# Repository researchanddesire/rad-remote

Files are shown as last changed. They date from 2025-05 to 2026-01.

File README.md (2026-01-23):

# RADR - OSSM Wireless Remote
**RADR** (pronounced like "radar") is a user friendly every day sex machine controller for the people. It's designed to simply and easily allow you to control many bluetooth sex toys, without reaching for your cellphone.

It was originally designed to control the [Open Source Sex Machine](https://docs.researchanddesire.com/ossm/guides/getting-started/introduction), but it can control much more!&#x20;

Check out the [user documentation](https://docs.researchanddesire.com/radr/guides/getting-started/introduction)

You can purchase complete remotes and OSSM kits on our shop - [RADR Product Page](https://www.researchanddesire.com/products/radr-ossm-wireless-remote)
<p align="center">
  
</p>

## **Community**
#### [**KinkyMakers Discord Community**](https://discord.gg/VtZcudpxT6)


Most OSSM development takes place through ideas and CAD contributions made by enthusiastic discord members, join the discussion or show off your build!

## Features:
* 4hr battery life
* Auto-pairing with your ossm via bluetooth
* 2" color screen for showing all your settings
* Supports Lovense bluetooth toys (roadmap to support every toy on [buttplug.io](https://buttplug.io/): complete list [here](https://iostindex.com/))
* QWIIC connector for modding and expansion
* Quick start-stop button
* 6-DoF gryo for activity detection (and fun future features)
* Battery fuel gauge
* Haptic feedback
* Audio tone generator

## Why we made it

We wanted an open source wireless remote that could control not just the ossm, but all our fun BLE devices!

## Future Roadmap
* Full [IOST device list](https://iostindex.com) support
* DG labs Coyote e-stim support
* Ability to synchronize or orchestrate multiple devices
* Dynamic pattern alteration on-remote

CERN Open Hardware Licence Version 2 - Strongly Reciprocal
Contributions to this GitHub repository will assume release under the same license.

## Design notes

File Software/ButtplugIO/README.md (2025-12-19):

Device Configurations Attribution

These device configurations were copied from the Buttplug IO project on Tuesday, October 14, 2025.

- Source repository: https://github.com/buttplugio/buttplug
- Project homepage: https://buttplug.io

We love the Buttplug project and are grateful for their work!

Notes

- The schema referenced here is aligned with Buttplug's v4 device configuration schema (`buttplug-device-config-schema-v4.json`).
- Please refer to the Buttplug repository for the latest updates and documentation, as well as licensing information (BSD 3-Clause): https://github.com/buttplugio/buttplug/blob/master/LICENSE

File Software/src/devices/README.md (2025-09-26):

### Devices Module

Technical documentation for developers adding new BLE devices to the remote.

## Supported Devices

- **Research And Desire**
  - **OSSM**: Supported
  - **LKBX**: Pending
  - **DTT**: Pending
- **Lovense**
  - **Domi 2**: Pending

## Registry Overview

Devices are discovered by their primary service UUID and instantiated via a factory registry.

- Registry map: `src/devices/registry.hpp`
- Known service UUIDs: `src/devices/serviceUUIDs.h`
- Device base class: `src/devices/device.h`

## How to Add a Device to the Registry

1. **Obtain the service UUID**

- Use a Bluetooth sniffing/inspection tool (e.g., Bluetility on macOS) to find the device's primary service UUID.

2. **Add the service UUID to `serviceUUIDs.h`**

- Store the UUID as a PROGMEM string constant.

```cpp
// src/devices/serviceUUIDs.h
static const char NEW_DEVICE_SERVICE_ID[] PROGMEM = "xxxxxxxx-xxxx-xxxx-xxxx-xxxxxxxxxxxx";
```

3. **Register a factory in `registry.hpp`**

- Include your device header and add an entry mapping the service UUID to a factory that returns a `Device*` of your concrete class.

```cpp
// src/devices/registry.hpp
#include "your_vendor/your_device/your_device.h"

static const std::unordered_map<String, DeviceFactory> registry = {
    {OSSM_SERVICE_ID, []() -> Device* { return new OSSM(); }},
    {DOMI_SERVICE_ID, []() -> Device* { return new Domi2(); }},
    {NEW_DEVICE_SERVICE_ID, []() -> Device* { return new YourDeviceClass(); }}
};
```

4. **Provide a concrete `Device` implementation**

- Create a header/implementation pair for your device that derives from `Device` (see `src/devices/device.h`).
- **Preferred file structure:**  
  Place your files in  
  `/src/devices/<brand_name>/<device_name>/<device>_device.h`  
  `/src/devices/<brand_name>/<device_name>/<device>_device.cpp`  
  For example, for a "FooBar" device from "Acme", use:  
  `/src/devices/acme/foobar/foobar_device.h`  
  `/src/devices/acme/foobar/foobar_device.cpp`

- Implement input handlers, drawing, and value sync methods as needed.

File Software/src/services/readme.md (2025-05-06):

# Services

Services are global singleton instances of classes that provide functionality to peripherals in the system. They are designed to be shared resources that can be accessed by different parts of the application.

## Key Characteristics

- Services are implemented as global singleton instances
- Typically, there is only one instance of each service running at any time
- By default, services are not thread-safe and require proper synchronization
- Services should be accessed using semaphores to ensure thread safety

## Creating a New Service

### Header File (ServiceName.h)

```cpp
#ifndef SERVICE_NAME_H
#define SERVICE_NAME_H

#include <Arduino.h>
#include "XYZ.h"

// Declare the global service instance, but do not initialize it
extern XYZ serviceNameInstance;

// Optional: Add service configuration or constants
#define SERVICE_NAME_MAX_CONNECTIONS 5

#endif // SERVICE_NAME_H
```

### Implementation File (ServiceName.cpp)

```cpp
#include "ServiceName.h"

// Initialize the global service instance
XYZ serviceNameInstance();

// Optional: Add initialization code in setup()
void setup() {
    serviceNameInstance.begin();
}
```

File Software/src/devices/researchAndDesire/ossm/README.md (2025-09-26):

# OSSM BLE Control Library - Basics

## Service & Device Info

- **Service UUID**: `522b443a-4f53-534d-0001-420badbabe69`
- **Device Name**: "OSSM"
- **Manufacturer**: "Research And Desire"

## Active Characteristics

### 1. Command Characteristic (Write)

- **UUID**: `522b443a-4f53-534d-0002-420badbabe69`
- **Purpose**: Send control commands

**Commands**:

```
set:speed:<0-100>        # Stroke speed percentage
set:stroke:<0-100>       # Stroke length percentage
set:depth:<0-100>        # Penetration depth percentage
set:sensation:<0-100>    # Sensation intensity percentage
set:pattern:<0-6>        # Stroke pattern (0-6)
go:simplePenetration     # Switch to simple penetration mode
go:strokeEngine          # Switch to stroke engine mode
go:menu                  # Return to main menu
```

**Responses**:

- Success: `ok:<original_command>`
- Failure: `fail:<original_command>`

### 2. State Characteristic (Read/Notify)

- **UUID**: `522b443a-4f53-534d-1000-420badbabe69`
- **Purpose**: Monitor device state and settings

**State JSON Format**:

```json
{
  "state": "<state_name>",
  "speed": <0-100>,
  "stroke": <0-100>,
  "sensation": <0-100>,
  "depth": <0-100>,
  "pattern": <0-6>
}
```

**Key States**:

- `idle` - Initializing
- `menu` - Main menu
- `simplePenetration` - Simple penetration mode
- `strokeEngine` - Stroke engine mode
- `error` - Error state

### 3. Speed Knob Config Characteristic (Write)

- **UUID**: `522b443a-4f53-534d-0010-420badbabe69`
- **Purpose**: Configure speed knob behavior

**Values**:

- `true` - Speed knob acts as upper limit for BLE commands (default)
- `false` - Speed knob and BLE speed are independent

### 4. Pattern List Characteristic (Read)

- **UUID**: `522b443a-4f53-534d-2000-420badbabe69`
- **Purpose**: Get available stroke patterns

**Pattern JSON Format**:

```json
[
  { "name": "Simple Stroke", "idx": 0 },
  { "name": "Teasing Pounding", "idx": 1 },
  { "name": "Robo Stroke", "idx": 2 },
  { "name": "Half'n'Half", "idx": 3 },
  { "name": "Deeper", "idx": 4 },
  { "name": "Stop'n'Go", "idx": 5 },
  { "name": "Insist", "idx": 6 }
]
```

## Connection Flow

1. Scan for "OSSM" device
2. Connect and discover service
3. Subscribe to state notifications
4. Read initial state and patterns
5. Send commands as needed

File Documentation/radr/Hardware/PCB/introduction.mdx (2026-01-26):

---
title: "PCB Overview"
description: "Technical documentation for the RADR main PCB (OSSM Wireless v0.4)"
sidebarTitle: "Introduction"
---

This section covers the RADR main PCB design, including schematics, component specifications, and manufacturing files.

## Board Overview

| Specification | Value |
|---|---|
| Board Name | OSSM Wireless |
| Version | v0.4 |
| Microcontroller | ESP32-S3 with PSRAM |
| Design Software | Altium Designer |
| Layer Count | 2 (estimated) |

The RADR PCB integrates all electronics required for a standalone wireless remote controller, including the microcontroller, display interface, power management, user inputs, and feedback systems.

<Frame>
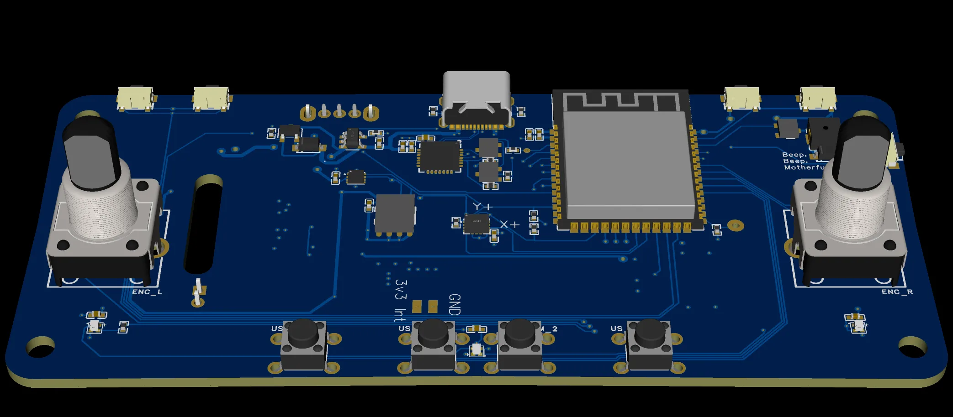
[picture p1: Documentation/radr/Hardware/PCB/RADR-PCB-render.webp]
RADR PCB Render

</Frame>

## Core Components

### Microcontroller

| Parameter | Value |
|---|---|
| MCU | ESP32-S3 |
| Memory | Includes PSRAM |
| Wireless | WiFi + Bluetooth LE |
| Operating Voltage | 3.3V |

The ESP32-S3 provides:
- Dual-core Xtensa LX7 processor
- Integrated Bluetooth Low Energy for device communication
- Sufficient GPIO for all inputs, outputs, and peripherals
- Low-power sleep modes for battery conservation

### Power Management

| Component | Function |
|---|---|
| USB-C Connector | 5V charging input |
| Charging IC | LiPo battery charging |
| MAX17048 | Fuel gauge (battery monitoring) |
| LDO/Regulator | 3.3V system power |

The power system supports:
- USB-C charging (5V input)
- Hardware charging LED indicator
- Precision battery percentage via I²C fuel gauge
- Deep sleep current < 100μA

### Display Interface

| Parameter | Value |
|---|---|
| Display Type | TFT LCD |
| Resolution | 320 x 240 pixels |
| Color Depth | 16-bit (RGB565) |
| Interface | SPI |
| Backlight | PWM-controlled |

### User Inputs

| Input | Type | GPIO |
|---|---|---|
| Left Encoder | Rotary + Push | GPIO 10, 11 |
| Right Encoder | Rotary + Push | GPIO 42, 41 |
| Left Shoulder | Momentary switch | GPIO 48 |
| Right Shoulder | Momentary switch | GPIO 1 |
| Under-Screen Left | Momentary switch | GPIO 38 |
| Under-Screen Center | Momentary switch | GPIO 39 |
| Under-Screen Right | Momentary switch | GPIO 40 |

<Note>
GPIO assignments shown are for v0.4 boards with PSRAM. Earlier v1.x boards use different pins for the left encoder (GPIO 35, 36) and LEDs (GPIO 37).
</Note>

### Feedback Outputs

| Component | Type | GPIO |
|---|---|---|
| Status LEDs | WS2812B RGB (x3) | GPIO 12 |
| Buzzer | Piezoelectric | GPIO 2 |
| Vibration Motor | ERM motor | GPIO 47 |

### Expansion

| Connector | Interface | Purpose |
|---|---|---|
| QWIIC | I²C | External sensors/peripherals |
| USB-C | USB 2.0 | Programming and charging |

## Schematic Sections

The schematic is organized into functional blocks:

| Section | Description |
|---|---|
| Power | USB-C input, charging circuit, voltage regulation |
| MCU | ESP32-S3, crystal, reset, boot selection |
| Display | TFT LCD connector, backlight driver |
| Inputs | Rotary encoders, buttons, pull-up/pull-down resistors |
| Feedback | LED data line, buzzer driver, motor driver |
| Battery | MAX17048 fuel gauge, battery connector |
| Expansion | QWIIC connector, programming header |

## PCB Layout Considerations

### Component Placement

- **MCU** positioned centrally for balanced trace routing
- **USB-C** connector at board edge for accessibility
- **Display connector** oriented for ribbon cable routing to enclosure
- **Battery connector** positioned for internal battery placement
- **QWIIC connector** accessible for expansion modules

### Antenna Considerations

The ESP32-S3 uses an integrated PCB antenna or external antenna (version dependent). The antenna area should be kept clear of:
- Ground planes directly beneath
- Metal enclosure proximity
- High-frequency switching signals

<Warning>
Do not place components or route traces in the antenna keepout zone. This significantly degrades wireless performance.
</Warning>

## Design Files

All design files are available in the GitHub repository:

| File | Format | Description |
|---|---|---|
| PCB - OSSM Wireless v0.4.pcbdoc | Altium Designer | PCB layout with copper, silkscreen, drill files |
| Schematic - OSSM Wireless V0.4.schdoc | Altium Designer | Full schematic capture |
| RADR Schematic - OSSM Wireless V0.4.pdf | PDF | Printable schematic reference |
| RADR BOM - OSSM Wireless - v0.4 - S3.xlsx | Excel | Bill of Materials with part numbers |
| RADR PCB render.png | PNG | 3D render of assembled board |

<Card title="Download Design Files" icon="download" href="https://github.com/researchanddesire/radr-wireless-remote/tree/main/Hardware/Electronics">
Access Altium project files, Gerbers, and BOM on GitHub.
</Card>

## Manufacturing

### PCB Fabrication

Recommended specifications for ordering:

| Parameter | Value |
|---|---|
| Layers | 2 |
| Thickness | 1.6mm |
| Surface Finish | HASL or ENIG |
| Copper Weight | 1oz |
| Solder Mask | Any color |
| Silkscreen | White |

### Assembly Options

| Method | Recommended For |
|---|---|
| Hand Assembly | Prototypes, single units |
| PCBA Service | Production quantities |

<Tip>
Services like JLCPCB and PCBWay offer combined PCB fabrication and assembly. Upload the Gerbers and BOM for a turnkey solution.
</Tip>

### Critical Components

These components require careful attention during assembly:

| Component | Notes |
|---|---|
| ESP32-S3 Module | Check orientation, ensure all pads are soldered |
| USB-C Connector | Requires precise alignment, check for shorts |
| MAX17048 | Small QFN package, needs proper reflow |
| WS2812B LEDs | Heat-sensitive, observe reflow profile |

## Version History

| Version | Changes |
|---|---|
| v0.4 | Current release with ESP32-S3 |

<Note>
Version v0.4 uses the ESP32-S3 variant. The "S3" suffix in the BOM filename indicates this variant.
</Note>

## Troubleshooting

<AccordionGroup>
<Accordion title="Board doesn't power on">
- Check USB-C connection and cable
- Verify 3.3V regulator output
- Check for shorts on power rails
- Ensure battery is connected and charged
</Accordion>

<Accordion title="Display not working">
- Verify ribbon cable connection
- Check SPI signals with oscilloscope
- Confirm backlight PWM signal
- Test display power rails
</Accordion>

<Accordion title="Bluetooth not connecting">
- Check antenna area for shorts or bridges
- Verify ESP32-S3 is programmed correctly
- Ensure no metal near antenna zone
- Test with RF shield removed (if applicable)
</Accordion>

<Accordion title="Battery not charging">
- Verify USB-C CC resistors are present
- Check charging IC connections
- Measure battery voltage at connector
- Confirm charging LED circuit
</Accordion>

<Accordion title="Buttons not responding">
- Check pull-up/pull-down resistors
- Verify GPIO assignments in firmware
- Test continuity from button to MCU
- Check for cold solder joints
</Accordion>
</AccordionGroup>

## Related Documentation

<CardGroup cols={2}>
<Card title="Hardware Overview" icon="microchip" href="/radr/Hardware/getting-started/introduction">
Complete hardware specifications and GPIO mappings.
</Card>

<Card title="Battery & Power" icon="battery-full" href="/radr/Hardware/specifications/battery-and-power">
Detailed power management and charging documentation.
</Card>

<Card title="Printed Parts" icon="cube" href="/radr/Hardware/printed-parts/introduction">
3D printed enclosure that houses the PCB.
</Card>

<Card title="Feedback Systems" icon="lightbulb" href="/radr/Hardware/specifications/feedback-and-indicators">
LED, buzzer, and vibration motor details.
</Card>
</CardGroup>

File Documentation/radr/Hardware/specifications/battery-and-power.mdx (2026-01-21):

---
title: "Battery and Power"
description: "Battery monitoring, charging, and power management for RADR"
sidebarTitle: "Battery & Power"
---

This guide covers RADR's battery system, charging, and power management features.

## Battery System

RADR uses a lithium battery with intelligent monitoring:

| Component | Description |
|---|---|
| Battery Type | Lithium Polymer (LiPo) |
| Fuel Gauge IC | MAX17048 |
| Charging Port | USB-C |
| Charging Indicator | Hardware LED |

### MAX17048 Fuel Gauge

The MAX17048 is a precision fuel gauge that provides:

- **Battery Percentage** — Accurate state-of-charge reading (0–100%)
- **Battery Voltage** — Real-time voltage measurement
- **Low Battery Alerts** — Programmable threshold notifications

<Info>
The fuel gauge uses proprietary algorithms to accurately estimate remaining battery life, compensating for factors like temperature and discharge rate.
</Info>

## Battery Indicator

The battery status is displayed in the status bar at the top of the screen:

| Level | Approximate Range |
|---|---|
| Full | 90–100% |
| High | 60–89% |
| Medium | 30–59% |
| Low | 10–29% |
| Critical | 0–9% |

<Warning>
When battery reaches critical levels, save your session and charge RADR to avoid unexpected shutdown.
</Warning>

## Charging

### USB-C Charging

RADR charges via the USB-C port located at the top of the device, next to the power switch.

- Connect any standard USB-C cable
- Compatible with USB chargers, power banks, and computer USB ports
- Charging works while RADR is powered on or off

### Charging Indicator

A hardware LED indicates charging status:

| LED State | Meaning |
|---|---|
| LED On | Charging in progress |
| LED Off | Fully charged or not connected |

<Note>
The charging LED is separate from RADR's software-controlled RGB LEDs. It's controlled directly by the charging circuit.
</Note>

<Note>
RADR relies on the hardware charging LED rather than software-based charging detection. This provides more accurate and reliable charging status indication.
</Note>

### Charging Tips

<Tip>
For fastest charging, use a USB charger rated for 5V/1A or higher.
</Tip>

<Tip>
You can use RADR while charging, but charging may take longer during active use.
</Tip>

## Power States

RADR has several power states:

### Active (Connected)

- Display on, backlight active
- Bluetooth connected to a device
- LEDs active
- Highest power consumption

### Active (Idle)

- Display on, backlight active
- Bluetooth scanning or in menu
- LEDs in idle pattern
- Medium power consumption

### Sleep Mode

- Display off, backlight off
- Bluetooth disabled
- LEDs off
- Very low power consumption
- GPIO wake enabled

### Power Off

- All systems off
- No power consumption
- Requires power switch to wake

## Deep Sleep Mode

Deep sleep provides significant power savings when you're not using RADR but want quick access later.

<Info>
Technically, RADR uses "light sleep" mode internally rather than true deep sleep. This provides more reliable button wake-up while still achieving very low power consumption. The user experience is the same—the device appears off until a button is pressed.
</Info>

### Entering Sleep Mode

1. From the main menu, select **Sleep**
2. RADR performs the shutdown sequence:
   - Disconnects any connected devices
   - Plays the shutdown buzzer sound
   - Turns off the display backlight
   - Clears all LEDs
   - Enters deep sleep

### Wake Sources

The following buttons can wake RADR from deep sleep:

| Button | GPIO |
|---|---|
| Under-Screen Center | GPIO 39 |
| Under-Screen Left | GPIO 38 |
| Under-Screen Right | GPIO 40 |

Press any of these buttons to wake RADR. The device performs a full restart.

### Sleep vs Power Off

| Feature | Sleep Mode | Power Off |
|---|---|---|
| Power consumption | Very low | None |
| Wake time | ~2 seconds | ~5 seconds |
| Wake method | Button press | Power switch |
| State preserved | No | No |
| Use case | Between sessions | Storage |

<Tip>
Use sleep mode during sessions with breaks. Use the power switch for extended storage.
</Tip>

## Power Management Tips

### Maximizing Battery Life

1. **Use sleep mode** — When taking breaks, put RADR to sleep instead of leaving it idle
2. **Lower brightness** — The display backlight is a significant power consumer
3. **Disconnect when done** — Active Bluetooth connections use more power
4. **Power off for storage** — Use the physical switch for extended storage

### Monitoring Battery Health

- Check battery percentage periodically in the status bar
- Charge before sessions to avoid mid-session interruptions
- Don't let the battery fully deplete frequently

### Charging Best Practices

- Use quality USB-C cables
- Charge in moderate temperatures (avoid extreme heat/cold)
- Any standard USB charger works (5V)
- Fully charge before first use

## Specifications

| Parameter | Value |
|---|---|
| Operating Voltage | 3.3V (regulated) |
| Charging Voltage | 5V USB |
| Deep Sleep Current | < 100μA |
| Active Current | Varies by activity |

## Troubleshooting

<AccordionGroup>
<Accordion title="Battery percentage seems inaccurate">
- The fuel gauge may need calibration after extended storage
- Fully charge, then fully discharge once to recalibrate
- Battery readings stabilize after a few charge cycles
</Accordion>

<Accordion title="RADR won't charge">
- Try a different USB-C cable
- Try a different USB power source
- Ensure the USB-C port is clean and undamaged
- Check that the charging LED illuminates when connected
</Accordion>

<Accordion title="Battery drains quickly">
- Check if you're leaving RADR in active/idle state
- Use sleep mode when not actively controlling a device
- Active Bluetooth connections consume more power
- Older batteries may have reduced capacity
</Accordion>

<Accordion title="Won't wake from sleep">
- Press and hold an under-screen button for 2-3 seconds
- Try the power switch if buttons don't respond
- Ensure the battery isn't completely depleted
</Accordion>
</AccordionGroup>

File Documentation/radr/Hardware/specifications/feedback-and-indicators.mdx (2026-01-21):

---
title: "Feedback and Indicators"
description: "LED colors, buzzer sounds, and vibration patterns for RADR"
sidebarTitle: "Feedback & Indicators"
---

RADR provides visual, audio, and haptic feedback to communicate device state without requiring you to look at the screen.

## LED System

RADR has three RGB LEDs (WS2812B) positioned around the device:

| Position | Location | Primary Purpose |
|---|---|---|
| LED 0 | Left encoder | Speed mode indicator |
| LED 1 | Middle | Connection/play state |
| LED 2 | Right encoder | Active mode indicator |

### LED Colors and Meanings

#### System States

| State | LED | Color | HSV Value | Brightness |
|---|-----|---|---|---|
| Searching/Scanning | All | Blue | 150 | 255 (pulsing) |
| Idle (Main Menu) | All | Soft White | 180 | 50 |
| Device Connected | Middle | White | — | 50 |
| Paused/Stopped | Middle | Red | — | 255 |

#### OSSM Control Modes

When controlling an OSSM, the encoder LEDs indicate the active mode:

| Mode | LED | Color | Description |
|---|-----|---|---|
| Speed | Left | Purple | Always active (speed is always controlled by left encoder) |
| Depth | Right | Coral/Red | Right encoder is adjusting depth |
| Sensation | Right | Blue | Right encoder is adjusting sensation |
| Stroke | Right | Green | Right encoder is adjusting stroke |

### LED Behavior Patterns

| Pattern | Meaning |
|---|---|
| Solid | Static state (connected, paused, etc.) |
| Pulsing | Active scan or searching |
| Quick flash | Feedback for button press or mode change |

## Buzzer Patterns

RADR uses a piezoelectric buzzer (GPIO 2) to provide audio feedback for key events.

### Boot Sound

**Pattern:** 4-note ascending sequence

| Note | Frequency | Duration |
|---|---|---|
| 1 | 523 Hz (C5) | 100ms |
| 2 | 659 Hz (E5) | 100ms |
| 3 | 784 Hz (G5) | 100ms |
| 4 | 1047 Hz (C6) | 150ms |

Played when RADR powers on.

### Shutdown Sound

**Pattern:** 4-note descending sequence

| Note | Frequency | Duration |
|---|---|---|
| 1 | 1047 Hz (C6) | 100ms |
| 2 | 784 Hz (G5) | 100ms |
| 3 | 659 Hz (E5) | 100ms |
| 4 | 523 Hz (C5) | 150ms |

Played when entering sleep mode.

### Device Connected

**Pattern:** 3-note ascending sequence

| Note | Frequency | Duration |
|---|---|---|
| 1 | 1047 Hz (C6) | 80ms |
| 2 | 1319 Hz (E6) | 80ms |
| 3 | 1568 Hz (G6) | 120ms |

Played when successfully connecting to a device.

### Device Disconnected

**Pattern:** 3-note descending sequence

| Note | Frequency | Duration |
|---|---|---|
| 1 | 1568 Hz (G6) | 80ms |
| 2 | 1319 Hz (E6) | 80ms |
| 3 | 1047 Hz (C6) | 120ms |

Played when a device disconnects.

### Paused

**Pattern:** Double beep

| Note | Frequency | Duration |
|---|---|---|
| 1 | 800 Hz | 150ms |
| Gap | — | 100ms |
| 2 | 800 Hz | 150ms |

Played when pausing playback.

### Play/Resume

**Pattern:** Two-tone ascending

| Note | Frequency | Duration |
|---|---|---|
| 1 | 1200 Hz | 100ms |
| 2 | 1400 Hz | 100ms |

Played when resuming playback.

### Mario Coin (Easter Egg)

**Pattern:** Classic coin sound

| Note | Frequency | Duration |
|---|---|---|
| 1 | 2637 Hz (E7) | 80ms |
| 2 | 3136 Hz (G7) | 300ms |

Special feedback for certain interactions.

## Vibration Feedback

RADR includes a vibration motor (GPIO 47) for haptic feedback. Vibration patterns generally mirror buzzer patterns, providing tactile feedback that works without sound.

### Vibration Use Cases

| Event | Vibration |
|---|---|
| Button press | Short pulse |
| Mode change | Quick vibration |
| Connection | Double vibration |
| Pause/Stop | Strong vibration |

### Vibration Pattern Timings

| Pattern | Description | Pulse Durations (ms) |
|---|---|---|
| Single Pulse | Quick tap feedback | 50 |
| Double Pulse | Confirmation feedback | 50, pause 200, 50 |
| Triple Pulse | Strong confirmation | 10, pause 50, 20, pause 50, 30 |
| Error Pulse | Long error indication | 500 |
| Shutdown | Descending pulses | 150, 100, 100, 100 |
| Device Connected | Ascending pulses | 100, 100, 150 |
| Device Disconnected | Descending pulses | 150, 100, 100 |
| Paused | Double pulse | 150, 150 |
| Play/Resume | Quick double pulse | 100, 100 |

<Info>
Vibration feedback helps you operate RADR by feel, especially useful in low-light or when the device is out of direct view.
</Info>

## UI Color Scheme

RADR's display uses a consistent color scheme:

### Background Colors

| Element | Color Code | Description |
|---|---|---|
| Background | 0x10c5 | Dark gray (Gray 900) |
| Text Background | White | Primary text color |
| Secondary Text | 0xDEFB | Light gray |
| Disabled | 0x1082 | Very dark gray |

### OSSM Mode Colors

| Mode | Color Code | Color Name |
|---|---|---|
| Speed | 0x5013 | Royal Purple |
| Depth | 0xE186 | Warm Coral |
| Sensation | 0x3C9F | Ocean Blue |
| Stroke | 0x4E8A | Forest Green |

### State Colors

| State | Color |
|---|---|
| Active/Normal | White |
| Paused/Stopped | Red |
| Disabled | Dark Gray |
| Selected/Highlighted | Accent colors |

## Feedback Timing

| Event | Response Time |
|---|---|
| Button press | < 10ms |
| Encoder change | < 10ms |
| Mode switch | < 50ms |
| LED color change | < 20ms |

## Tips for Using Feedback

<Tip>
Learn the buzzer sounds to operate RADR without looking. The connected sound (ascending) vs disconnected sound (descending) clearly indicates state.
</Tip>

<Tip>
The left LED (purple for speed) and right LED (mode color) tell you which parameter each encoder controls at a glance.
</Tip>

<Tip>
Red middle LED always means paused or stopped. White means active and ready.
</Tip>

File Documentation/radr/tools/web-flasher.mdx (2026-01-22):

---
title: "Web Flasher"
description: "Flash firmware to your RADR wireless remote using the browser-based web flasher utility"
---

import { DeviceFlasher } from '/snippets/shared/device-flasher.jsx';

<DeviceFlasher device="radr" />

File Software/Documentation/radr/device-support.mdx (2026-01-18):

---
title: "Device Support"
description: "Complete list of devices officially supported by the Research And Desire Wireless Remote (RADR)"
---

# Device Support

Every device on this list will be evaluated for RADR compatibility throughout 2025 and 2026.

<Info>
Want us to prioritize a specific device or add one to this list? Contact our support team at [support@researchanddesire.com](mailto:support@researchanddesire.com) or through our [contact form](https://www.researchanddesire.com/contact).
</Info>

## Research And Desire Devices

| Device | Supported | Tested |
| --- | --- | --- |
| [Open Source Sex Machine](https://www.researchanddesire.com/open-source-sex-machine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) | Yes | Yes |
| [Chastity Lockbox](https://www.researchanddesire.com/lockbox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) | Pending | - |
| [Deepthroat Trainer](https://www.researchanddesire.com/deepthroat-trainer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) | Pending | - |

## Third Party Devices

| Device | Supported | Tested |
| --- | --- | --- |
| [DG Labs Coyote E-Stim Powerbox 3.0](https://dungeon-lab.com/e-stim-unit3.0.php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) | Pending | - |

## Buttplug.io Devices

Through our partnership with [Buttplug.io](https://buttplug.io/), we support every device compatible with their Bluetooth protocol. Check their website for the most current compatibility list.

<Warning>
Untested devices display a warning message before use. Only use untested devices during sessions if you understand and accept the associated risks.
</Warning>

### Lovense (Tested)

| Device | Supported | Tested |
| --- | --- | --- |
| [Lovense Domi](https://www.lovense.com/super-powerful-wand-massager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) | Vibration Only | Yes |
| [Lovense Hyphy](https://www.lovense.com/high-frequency-dual-end-vibrator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) | Vibration Only | Yes |
| [Lovense Ferri](https://www.lovense.com/magnetic-panty-vibrator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) | Vibration Only | Yes |

### Lovense (Untested)

| Device | Supported | Tested |
| --- | --- | --- |
| [Lovense Max](https://www.lovense.com/male-masturbators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) | Vibration Only | - |
| [Lovense Edge](https://www.lovense.com/adjustable-prostate-massager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) | Vibration Only | - |
| [Lovense Nora](https://www.lovense.com/rabbit-vibrator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) | Vibration Only | - |
| [Lovense Ambi](https://www.lovense.com/mini-bullet-vibrator-for-clitoral-simulation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) | Vibration Only | - |
| [Lovense Lush](https://www.lovense.com/lush-4-best-bluetooth-remote-controlled-g-spot-vibrator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) | Vibration Only | - |
| [Lovense Hush](https://www.lovense.com/vibrating-butt-plug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) | Vibration Only | - |
| [Lovense Osci](https://www.lovense.com/oscillating-gspot-vibrator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) | Vibration Only | - |
| [Lovense Mission](https://www.lovense.com/mission-2-best-touch-sense-vibrating-dildo-with-suction-cup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) | Vibration Only | - |
| [Lovense Mission 2](https://www.lovense.com/mission-2-best-touch-sense-vibrating-dildo-with-suction-cup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) | Vibration Only | - |
| [Lovense Diamo](https://www.lovense.com/bluetooth-vibrating-cock-ring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) | Vibration Only | - |
| Loveai Dolp | Vibration Only | - |
| [Lovense Dolce](https://www.lovense.com/adjustable-dual-clit-gspot-vibrator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) | Vibration Only | - |
| [Lovense Osci 3](https://www.lovense.com/osci-3-gspot-clitoral-dual-stimulation-rabbit-vibrator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) | Vibration Only | - |
| [Lovense Gush](https://www.lovense.com/handsfree-glans-massager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) | Vibration Only | - |
| [Lovense Gush 2](https://www.lovense.com/gush-2-best-remote-controlled-vibrating-male-penis-massager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) | Vibration Only | - |
| [Lovense Calor](https://www.lovense.com/vibrating-pocket-pussy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) | Vibration Only | - |
| [Lovense Flexer](https://www.lovense.com/dual-wearable-panty-vibrator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) | Vibration Only | - |
| [Lovense Gemini](https://www.lovense.com/app-controlled-vibrating-nipple-clamps-clit-clamps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) | Vibration Only | - |
| [Lovense Gravity](https://www.lovense.com/thrusting-vibrating-dildo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) | Vibration Only | - |
| [Lovense Tenera](https://www.lovense.com/tenera-2-best-clit-sucker-vibrator-clitoral-stimulator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) | Vibration Only | - |
| [Lovense Ridge](https://www.lovense.com/ridge-vibrating-rotating-anal-beads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) | Vibration Only | - |
| [Lovense Lapis](https://www.lovense.com/lapis-strapless-strap-on-double-sided-dildo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) | Vibration Only | - |
| [Lovense Vulse](https://www.lovense.com/vulse-wireless-g-spot-egg-vibrator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) | Vibration Only | - |
| [Lovense Solace](https://www.lovense.com/solace-automatic-hands-free-male-masturbator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) | Pending | - |
| [Lovense Solace Pro](https://www.lovense.com/solace-pro-ai-automatic-blowjob-machine-men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) | Pending | - |

### Other Brands (Pending Support)

<AccordionGroup>
<Accordion title="Adrien Lastic">
- Adrien Lastic Palpitation
- Adrien Lastic Revelation
</Accordion>

<Accordion title="Amorelie Joy">
- Amorelie Joy Move
- Amorelie Joy Cha-Cha
- Amorelie Joy Boogie
- Amorelie Joy Shimmer
- Amorelie Joy Grow
- Amorelie Joy Shuffle
- Amorelie Joy Salsa
</Accordion>

<Accordion title="Adorime">
- Adorime Wearable Egg Vibrator
- Adorime Male Masturbator
- Adorime Penis Vibrator
- Adorime Anal Vibrator
- Adorime Chastity Cage
- Adorime Penis Helmet Vibrator
- Adorime G-spot Rabbit Dildo Vibrator
- Adorime Backy
</Accordion>

<Accordion title="Auxfun / Hismith / Defyeah / Wildolo">
- Auxfun Sex Machine
- Hismith Sex Machine
- Hismith Mini Sex Machine
- Hismith Servo Sex Machine
- Hismith Ukulele
- Hismith Pro Traveler
- Hismith Capsule
- Hismith Thrusting Cup
- Hismith G011
- Wildolo Device
- Defyeah Horizontal Sex Machine ASFO16
</Accordion>

<Accordion title="Cachito">
- Cachito Lure Tao
- Cachito Ice Cream
</Accordion>

<Accordion title="The Cowgirl / Unicorn">
- The Cowgirl Cone
- The Cowgirl
- The Unicorn
</Accordion>

<Accordion title="Cueme">
- Cueme Mens
- Cueme Bra
- Cueme Womans
</Accordion>

<Accordion title="Eropair / Sinloli">
- Eropair Rabbit Vibrator
- Eropair Thrusting Vibrating Dildo
- Eropair Cup
- Sinloli Automatic Sex Doll
- Sinloli Cosima
- Sinloli Ethel
- Sinloli Aston
- Sinloli Piupiu
</Accordion>

<Accordion title="Foreo">
- Foreo LUNA fofo
- Foreo LUNA play smart 2
- Foreo LUNA 3 / 3 plus / 3 men / 3 mini
- Foreo LUNA 4 / 4 plus / 4 men / 4 mini
- Foreo UFO / UFO mini / UFO 2
- Foreo UFO 3 / 3 go / 3 led / 3 mini
- Foreo BEAR / BEAR mini
- Foreo BEAR 2 / 2 go / 2 eyes / 2 body
- Foreo KIWI / KIWI derma
</Accordion>

<Accordion title="Galaku">
- Galaku Nebula
- Galaku Shana
- Galaku Miya
- Galaku Capsule lipstick
- Galaku Vitality Cat
- Galaku Phantom X
- Galaku Vitality Strawberry
- Galaku Little Magic Box
- Galaku Little Whale
- Galaku Happy Vibrator
- Galaku Xiaobao Beans
- Galaku Capsule Vibrator
- Galaku Ice cone miniAV stick
- Galaku mini ice cream cone
- Galaku Shia's Collar
- Galaku Vitality Bird (Second Generation)
- Galaku Octopus glans massager
- Galaku Alice
- Galaku Unicorn Butt Plug
- Galaku Ace
- Galaku Little cute turtle
- Galaku Little Bullet
- Galaku Joy Vibrator
- Galaku Bowling
- Galaku Mixin Controller
- Galaku Hua Chao Brush
- Galaku Dream Vibration
- Galaku Rogue Rabbit
- Galaku Ballet Vibrator
- Galaku Donut
- Galaku Flirting Pen
- Galaku Ball vibrator
- Galaku Cyberpunk Airplane Cup
- Galaku Vitality Cute Pet
- Galaku Little gourd vibrating egg
- Galaku little kitten
- Galaku Little Dinosaur
- Galaku Bell sucking
- Galaku Ring vibration
- Galaku Erection Booster
- Galaku Gyoyo-G
- Galaku Gyoyo
- Galaku Pinky stick
- Galaku Little Turtle Stick
- Galaku Xiao Xian Wan
- Galaku Mitang
- Galaku Zaku Aircraft Cup
- Galaku Mecha
- Galaku Little Devil
- Galaku Athena
- Galaku Vitality Octopus II
- Galaku Little Dolphin
- Galaku Unicorn / Unicorn II
- Galaku Queen Bee Gun
- Galaku Freya
- Galaku Rhino Prostate Massager
- Galaku Armoured-ONE
- Galaku Flower Season
- Galaku Little Rubik's Cube
- Galaku Small powder cake
- Galaku Milly
- Galaku Rhinoceros Back Court
- Galaku Phantom / Phantom PLUS
- Galaku F1 Aircraft Cup
- Galaku Scepter AV Stick
- Galaku Classic vibration-absorbing AV state
- Galaku New series of vibrators
- Galaku Aurora Aircraft Cup
- Galaku Cannon-GT
- Galaku Vision
- Galaku Dimension No. 1
- Galaku Starry Sky CUP
- Galaku Panty Vib
</Accordion>

<Accordion title="iToys">
- iToys Seagull
- iToys Twinkling Stars
</Accordion>

<Accordion title="JoyHub">
- JoyHub Pearlconch / Pearlconch L
- JoyHub Piet 2
- JoyHub Panther
- JoyHub Petite Rose
- JoyHub Moon Horn
- JoyHub Mecha
- JoyHub Lagoon
- JoyHub VibTrefoil
- JoyHub Firedragon
- JoyHub Deena
- JoyHub Cherly / Cherly 2c
- JoyHub Pathfinder / Pathfinder 2 / Pathfinder 3
- JoyHub Angela
- JoyHub Verax / Verax 2 / Verax 4
- JoyHub Euphoric / Euphoric 2 / Euphoric 3
- JoyHub RoseBUD
- JoyHub Morningbuds
- JoyHub Rhythmic 2 / Rhythmic 3 / Rhythmic 4
- JoyHub Virtuoso / Virtuoso 2
- JoyHub Dyllis
- JoyHub PhoenixGP
- JoyHub Fable Dragon
- JoyHub Faunus
- JoyHub Velvet Rabbit
- JoyHub Vivid Pulse
- JoyHub Violet Vine
- JoyHub VibSiren / VibSiren 2
- JoyHub Veemy
- JoyHub Viball
- JoyHub Vase / Vase 2
- JoyHub Vortex 2s
- JoyHub Lips
- JoyHub Torin
- JoyHub VBarbie / VBarbie p
- JoyHub Royaleye
- JoyHub Norma
- JoyHub Pau
- JoyHub Petalwish 2 / Petalwish 3
- JoyHub Marshal
- JoyHub Vince
- JoyHub Dallin
- JoyHub Maynor
- JoyHub Palmyra
- JoyHub Xylia
- JoyHub Maiden
- JoyHub Viele / Viele 3
- JoyHub Troi
- JoyHub Tanmouth
- JoyHub Marcela
- JoyHub Vita
- JoyHub Lach
- JoyHub Markel
- JoyHub Pipes
- JoyHub Vigo
- JoyHub Starfish
- JoyHub Resi Ring 2
- JoyHub RoseLin
- JoyHub Perseus
- JoyHub Melody
- JoyHub Rosella 2
- JoyHub Velocity
- JoyHub ElixirEgg
- JoyHub Retro Guard
- JoyHub TrueForm / TrueForm 3
- JoyHub Rainbow
- JoyHub Black Bull
- JoyHub Peacock
- JoyHub Mace
- JoyHub Tarian
- JoyHub Torrian
- JoyHub Rayen
- JoyHub Mackay
- JoyHub Rowdy 3
- JoyHub Eclipse
- JoyHub Scarlett
- JoyHub Tarik
- JoyHub Urica Guard / Urica Guard 2
- JoyHub Viva
- JoyHub Ryden
- JoyHub Peachy
- JoyHub Enam
- JoyHub Viv
- JoyHub Vivara
- JoyHub Explorer 2
- JoyHub Divers
- JoyHub Vortex Tongue
- JoyHub Mysticolor
- JoyHub Vivid Wings
- JoyHub Mariner
- JoyHub MarsLion / Mars Lion 2
- JoyHub Pul
- JoyHub Rose Love
- JoyHub Edasich
- JoyHub Mars
- JoyHub Martino
- JoyHub Myrna
</Accordion>

<Accordion title="Kiiroo / OhMiBod / Hot Octopuss">
- Luxus
- Kiiroo Pearl / Pearl 2 / Pearl 2.1 / Pearl 2+ / Pearl 3
- Kiiroo Onyx / Onyx 2 / Onyx 2.1 / Onyx+ / Onyx+ Realm Edition
- Kiiroo Titan / Titan 1.1
- Kiiroo Cliona
- Kiiroo Keon
- Kiiroo PleasureDrive
- Fleshlight Launch
- OhMiBod Fuse / Fuse 1.1
- OhMiBod Esca 2
- OhMiBod Lumen
- OhMiBod NEX|2 / NEX|3
- OhMiBod Foxy
- OhMiBod Chill
- OhMiBod Sphinx
- PornHub Virtual Rabbit
- PornHub Virtual Blowbot
- Hot Octopuss Pulse Solo Interactive
</Accordion>

<Accordion title="Kisstoy">
- Kisstoy Lost (Vibrating)
- Kisstoy Lost (Sucking)
- Kisstoy Lost (Insertable)
</Accordion>

<Accordion title="Kuirkish">
- Kuirkish Imp 3
</Accordion>

<Accordion title="LELO">
- Lelo F1s V2 / V3
- Lelo F2S
- Lelo Ida Wave
- Lelo Tor 3
- Lelo Hugo 2
- Lelo Enigma Double Sonic
- Lelo Gigi 3
- Lelo Liv 3
</Accordion>

<Accordion title="Libo">
- Libo Elle / Elle 2
- Libo Lottie
- Libo LuLu
- Libo Lina
- Libo Adel
- Libo Lily
- Libo Lucy
- Libo Lara
- Libo Feather
- Libo LaLa
- Libo Carlos
- Libo Selina
- Libo Miao
</Accordion>

<Accordion title="Love Distance">
- Love Distance Reach G
- Love Distance Reach
- Love Distance Mag
- Love Distance Span
- Love Distance Range
- Love Distance Join G
- Love Distance Link
- Love Distance Grasp
- Love Distance Receive
</Accordion>

<Accordion title="Lovehoney">
- Lovehoney Desire Prostate Vibrator
- Lovehoney Desire Knicker Vibrator
- Lovehoney Desire Love Egg
</Accordion>

<Accordion title="Lovense Connect">
- Lovense Connect Max
- Lovense Connect Edge
- Lovense Connect Nora
- Lovense Connect Ambi
- Lovense Connect Lush
- Lovense Connect Hush
- Lovense Connect Domi
- Lovense Connect Osci
- Lovense Connect Mission
- Lovense Connect Ferri
- Lovense Connect Diamo
- Lovense Connect Loveai Dolp
- Lovense Connect Sex Machine / Mini Sex Machine
- Lovense Connect Dolce
- Lovense Connect Gush
- Lovense Connect Hyphy
- Lovense Connect Calor
- Lovense Connect Flexer
- Lovense Connect Gemini
- Lovense Connect Gravity
- Lovense Connect Ridge
- Lovense Connect Lapis
- Lovense Connect Vulse
- Lovense Connect Solace
</Accordion>

<Accordion title="Luvmazer">
- Luvmazer Finger Magic
- Luvmazer Cat Paw
- Luvmazer Cock Ring
- Luvmazer Interstellar
</Accordion>

<Accordion title="MagicMotion / FitCute / G Vibe / FunTown / Femometer">
- MagicMotion Smart Bean
- MagicMotion Smart Mini Vibe
- MagicMotion Vini
- MagicMotion Flamingo
- MagicMotion Kegel
- MagicMotion Dante/Candy/Rise
- MagicMotion Wand
- MagicMotion Fugu
- MagicMotion Xone
- MagicMotion Awaken
- MagicMotion Equinox
- MagicMotion Solstice / Solstice X
- MagicMotion Eidolon
- MagicMotion Zenith
- MagicMotion Bunny
- MagicMotion Sundae
- MagicMotion Kegel Coach
- MagicMotion Lotos
- MagicMotion Nyx
- MagicMotion Umi
- MagicMotion Crystal
- MagicMotion Bobi
- FitCute Kegel Rejuve
- G Vibe Gballs 2 / Gballs 3
- FunTown Caleo
- FunTown Jive
- Femometer Lilac
</Accordion>

<Accordion title="Meese / Sistalk / Tracy's Dog">
- Meese Tera
- Meese Modo
- Sistalk MonsterPub 2 Doctor Whale
- Sistalk MonsterPub Magic Kiss
- Sistalk MonsterPub 2 Mister Devil
- Sistalk MonsterPub Baby Youth Health
- Sistalk MonsterPub KiniCat
- Sistalk MonsterPub BeatHeart
- Sistalk MonsterPub 1P Mister Devil
- Sistalk MonsterPub Sweet
- Sistalk MonsterPub Amazing
- Sistalk MonsterHub Tornado
- Sistalk MonsterPub Pop
- Tracy's Dog Surreal
- Tracy's Dog Craybit Pro
</Accordion>

<Accordion title="Motorbunny / Dream Lover">
- Motorbunny Classic
- Motorbunny Buck
- Dream Lover Archer 2
</Accordion>

<Accordion title="MysteryVibe">
- MysteryVibe Tenuto Mini
- MysteryVibe Crescendo / Crescendo 2
- MysteryVibe Tenuto / Tenuto 2
- MysteryVibe Legato
- MysteryVibe Molto
- MysteryVibe Poco
</Accordion>

<Accordion title="Patoo / Picobong">
- Patoo Carrot
- Patoo Vibrator
- Patoo Bean Sprout
- Patoo Devil
- Picobong Blow hole
- Picobong Diver
- Picobong Life guard
- Picobong Surfer
</Accordion>

<Accordion title="Pink Punch / Sakuraneko">
- Pink Punch Sunset Mushroom
- Pink Punch Peachu
- Pink Punch Dream Bunny
- Pink Punch Peacaron
- Sakuraneko Korokoro
- Sakuraneko Nukunuku
- Sakuraneko Dokidoki
- Sakuraneko Koikoi
</Accordion>

<Accordion title="Satisfyer">
- Satisfyer Hot Spot
- Satisfyer Heated Affair
- Satisfyer Big Heat
- Satisfyer Heated Thrill
- Satisfyer Hot Bunny
- Satisfyer Heat Climax / Heat Climax+
- Satisfyer Hot Passion
- Satisfyer Haute Couture+
- Satisfyer High Fashion+
- Satisfyer Prêt-à-porter+
- Satisfyer Love Triangle
- Satisfyer Curvy 1+ / 2+ / 3+
- Satisfyer Double Wand-er
- Satisfyer Double Joy / Double Fun / Double Love
- Satisfyer Hot Lover
- Satisfyer Mono Flex / Double Flex
- Satisfyer Heat Wave
- Satisfyer Little Secret / Sexy Secret / Top Secret / Top Secret+
- Satisfyer Strong One / Mighty One / Powerful One / Royal One
- Satisfyer Signet Ring
- Satisfyer Dual Love / Dual Pleasure
- Satisfyer Hero+ / Knight+ / Newcomer+
- Satisfyer Plug-ilicious 1 / 2
- Satisfyer E-Love Foreplay / G-Hunter / G-Hunter+ / G-Spotter / G-Spotter+ / Story
- Satisfyer Love Birds 1 / 2 / Vary
- Satisfyer Ribbed Petal / Shiny Petal / Smooth Petal
- Satisfyer Men Vibration+
- Satisfyer Power Plug
- Satisfyer Rotator Plug 1+ / 2+
- Satisfyer Deep Diver
- Satisfyer Sweet Seal
- Satisfyer Trendsetter
- Satisfyer Twirling Joy
- Satisfyer Ultra Power Bullet 8
- Satisfyer Double Desire / Double Lust
- Satisfyer Epic Duo
- Satisfyer Pleasure Wand+
- Satisfyer Bullseye
- Satisfyer Sunray
- Satisfyer Curvy Trinity 5+
- Satisfyer Intensity Plug
- Satisfyer Power Masturbator
- Satisfyer Hug me
- Satisfyer Air Pump Bunny 5+ / Air Pump Vibrator 5+ / Air Pump Booty 5+
- Satisfyer Threesome 4
- Satisfyer G-Spot Flex 4+ / 5+
- Satisfyer Pro+ Wave 4
- Satisfyer Mini Wand-er+
- Satisfyer Tropical Tip
- Satisfyer Twirling Pro+
- Satisfyer Perfect Pair 4
- Satisfyer Booty Absolute Beginners 5
- Satisfyer Rrrolling Sensation
- Satisfyer Pro 2 Gen 3
</Accordion>

<Accordion title="SayberX / Sensee / Easylive / Qingnan">
- SayberX
- Sayber X-Ring
- Sensee Capsule
- Sensee Astronaut
- Sensee No8
- Sensee Voice-Interactive Female Vibrator
- Sensee Moonlight
- Sensee Little Seahorse
- Sensee Dream Stick
- Easylive Vader
- Qingnan #16
</Accordion>

<Accordion title="Secret Lover">
- Secret Lover Simon
- Secret Lover Betty
- Secret Lover Kevin
</Accordion>

<Accordion title="Sexverse / VVD / Cooxer / Duopeak">
- Sexverse Rex
- Sexverse Cali
- Sexverse Olis
- Sexverse BuCUE
- Sexverse Tadpole
- Sexverse Upton
- Sexverse Una
- Sexverse HH010
- Sexverse Tay 1 / 6 / 9
- Sexverse Zeus
- Sexverse Black Knight / Dark Knight
- VVD Vkini
- Cooxer Bullet Vibe
- Duopeak Saphette
</Accordion>

<Accordion title="Svakom / ToyCod / BeYourLover / Fantasy Cup / Coleur Dor / Momonii">
- Svakom Pulse Lite Neo
- Svakom Pulse Union
- Svakom Pulse Galaxie
- Svakom Mimiki
- Svakom Sam Neo 2 / Sam Neo 2 Pro
- Svakom Ella / Ella Neo
- Svakom Phoenix Neo / Phoenix Neo 2
- Svakom Emma Neo / Emma Neo 2 / Mini Emma Neo
- Svakom Viviana
- Svakom Edeny
- Svakom Tammy Pro
- Svakom Vick Neo / Vick Neo 2
- Svakom Aravinda
- Svakom Winni 2
- Svakom Cici 2 / Cici+ 2
- Svakom Hannes Neo
- Svakom Alberta
- Svakom Erica
- Svakom Chika
- Svakom Mora Neo
- Svakom Trysta Neo
- Svakom Coco Pro
- Svakom Echo 2
- Svakom Iker Neo
- ToyCod Vanesia
- ToyCod Barzillai
- ToyCod Clara
- BeYourLover Kyukyu
- BeYourLover Naughty Clock Vibrator / Sucker
- Fantasy Cup Theodore
- Coleur Dor VX045A / HX029A / VX236A
- Momonii Agatha
</Accordion>

<Accordion title="Synchro / TryFun / VibCrafter / Vibratissimo">
- Synchro Exchange
- TryFun Surge Pro
- VibCrafter Harlow
- VibCrafter Hayden
- VibCrafter Nidalee
- VibCrafter Janna
- Vibratissimo Licker
- Vibratissimo Rabbit
</Accordion>

<Accordion title="Vorze / Adult Festa">
- Vorze Bach
- Vorze A10 Cyclone SA
- Vorze UFO SA / UFO TW
- Vorze Piston
- Adult Festa Rocket
</Accordion>

<Accordion title="We-Vibe">
- We-Vibe Melt
- We-Vibe Moxie
- We-Vibe Vector
- We-Vibe Wand / Wand 2
- We-Vibe Bond
- We-Vibe Nova / Nova 2
- We-Vibe Jive / Jive 2
- We-Vibe Sync / Sync 2 / Sync Lite
- We-Vibe Bloom
- We-Vibe Ditto
- We-Vibe Pivot
- We-Vibe Rave
- We-Vibe Verge
- We-Vibe Wish
- We-Vibe 4 Plus
- We-Vibe Gala
</Accordion>

<Accordion title="Zalo">
- Zalo Queen
- Zalo King
- Zalo Jeanne
</Accordion>
</AccordionGroup>

<Note>
Affiliate links are marked with a star icon and help fund continued development of this project.
</Note>

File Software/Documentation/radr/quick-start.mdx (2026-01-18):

---
title: "Quick Start"
description: "Get your Research And Desire Wireless Remote (RADR) set up and connected to your OSSM or Bluetooth device in minutes."
---

<iframe
  className="w-full aspect-video rounded-xl"
  src="https://www.youtube.com/embed/SqUHOGLTgAE"
  title="RADR Quick Start Video"
  frameBorder="0"
  allow="accelerometer; autoplay; clipboard-write; encrypted-media; gyroscope; picture-in-picture"
  allowFullScreen
></iframe>

<Accordion title="Video transcript">
Today I have the new Research and Desire wireless remote, also called the RADR. And I'm super excited to show you how it connects with both OSSM and also a wireless Bluetooth device like the Domi right here. In order to control the OSSM, you have to make sure that you have updated your firmware to the newest version. Once you've done that, just make sure that your machine is plugged in and turned on. And I'll show you how it connects really quickly. I'm turning on the power switch. And as you can see, it is automatically searching for the device and voila, it is connected. You don't have to do anything else. I'll go over some of the specifics of the remote now. So the left hand knob always is controlling the speed and the right hand knob will toggle back and forth depth, sensation, and stroke. So I'm just going to turn up the speed a little bit here so you can see that's going. And right now I'm currently in stroke. As I'm moving the stroke knob, you can see one of the rings is going up and down. So you can always kind of see where you're at in terms of how much stroke you have on. In terms of these buttons here, this button here is pattern. So if you click into it, you'll be able to take a look at all the different patterns. and you can select one using the pattern button again. This button here is stop and go, pause or play. So there we go, it stopped your OSSM immediately and then it says if you click it again, device is stopped. Once it stops you can just like turn up the speed again and it'll start working again. And that's it for controlling the OSSM. So I also wanted to show you how to control the Domi, so I'm just gonna turn this off and I'm gonna unplug my OSSM. Alright, so now I've got my Domi and I'm just gonna turn it on. So it's on now and I'm gonna just do the same thing like I did with the OSSM. I turn it on and it's gonna automatically search for the device. And look at that, it is connected to my Domi now. I can play with the knob. And there's that stop button as well. And there you have it, you have the new wireless remote radar connecting both to the Domi and to the OSSM.
</Accordion>

The RADR was originally designed as a wireless, user-friendly controller for the OSSM (Open-Source Sex Machine), created in partnership with The Kinkymakers. It has since evolved into a versatile wireless controller for a range of Bluetooth-enabled devices using the ButtplugIO protocol.

This guide walks you through pairing your RADR with the OSSM and getting started immediately. The same process applies to other supported devices like the Lovense Domi 2.

<Card title="Device support" icon="bluetooth" href="./device-support">
View the complete list of supported Bluetooth devices.
</Card>

## Getting started

### Remote layout

<Frame>
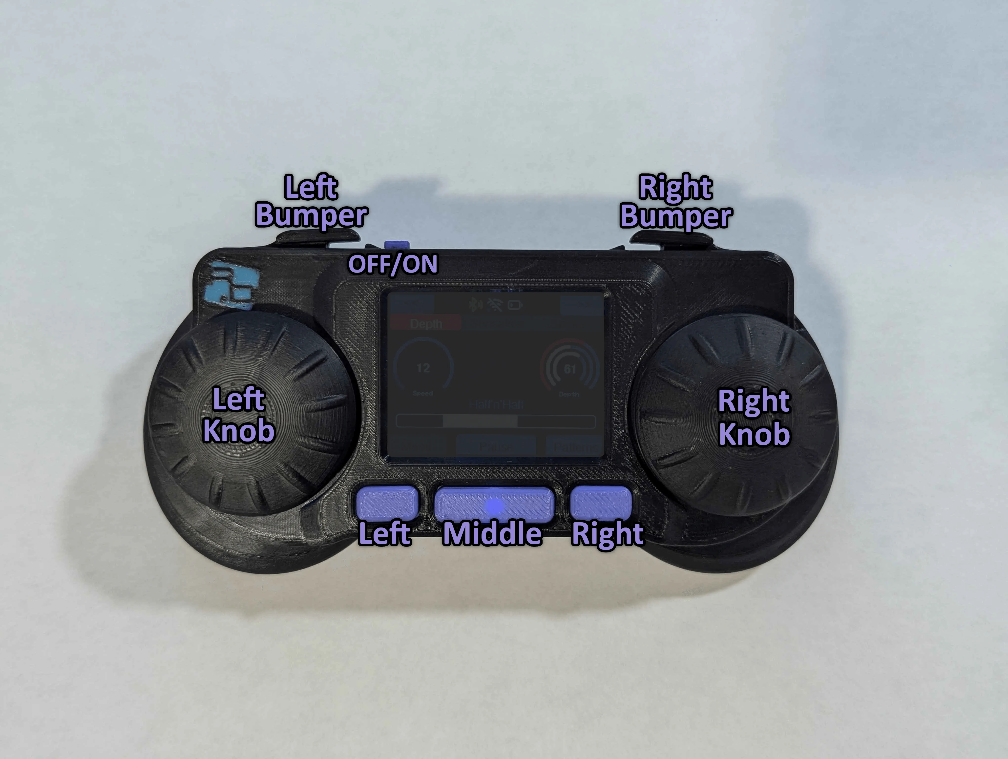
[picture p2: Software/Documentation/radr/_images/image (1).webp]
RADR remote control layout showing buttons, knobs, and screen placement

</Frame>

The RADR features an intuitive, tactile design with the following controls:

**Top edge:**
- **Left Bumper** — Located on the left side
- **Power Switch** — Above the screen, to the left of the USB-C port
- **Right Bumper** — Located on the right side

**Front face:**
- Full-color LCD screen centered on the device
- Three buttons directly below the screen:
  - **Left Button** — Home / Back
  - **Middle Button** — Pause / Stop
  - **Right Button** — Menu / OK

**Sides:**
- **Left Knob** (encoder) — Controls speed
- **Right Knob** (encoder) — Adjusts depth, sensation, or stroke

### Powering on

<Steps>
<Step title="Charge your RADR">
Connect your RADR to a power source using a USB-C cable and allow it to charge.
</Step>

<Step title="Turn on the remote">
Flip the **Power Switch** to the right (toward the USB-C port) to power on the device.
</Step>

<Step title="Wait for device discovery">
Once powered on, your RADR automatically scans for nearby supported Bluetooth devices.

<Info>
RADR only searches for officially supported devices. It won't connect to unsupported Bluetooth hardware.
</Info>
</Step>
</Steps>

<Card title="Device support" icon="list-check" href="./device-support">
Check which devices are compatible with RADR.
</Card>

### Pairing with the OSSM

<Steps>
<Step title="Update your OSSM firmware">
Ensure your OSSM is running firmware version 2.0.0 or higher.

<Card title="Flashing your OSSM" icon="microchip" href="/ossm/Software/getting-started/introduction">
Follow our firmware update guide if you need to update your OSSM.
</Card>
</Step>

<Step title="Power on and home the OSSM">
Turn on your OSSM and allow it to complete its homing procedure. Keep the device powered on.
</Step>

<Step title="Automatic pairing">
With both devices powered on and nearby, they will automatically pair within seconds.

<Check>
When connected, your RADR displays the Play Controls screen.
</Check>
</Step>
</Steps>

## Play controls

When your RADR and OSSM are paired, you'll see the Play Controls screen.

<Frame>
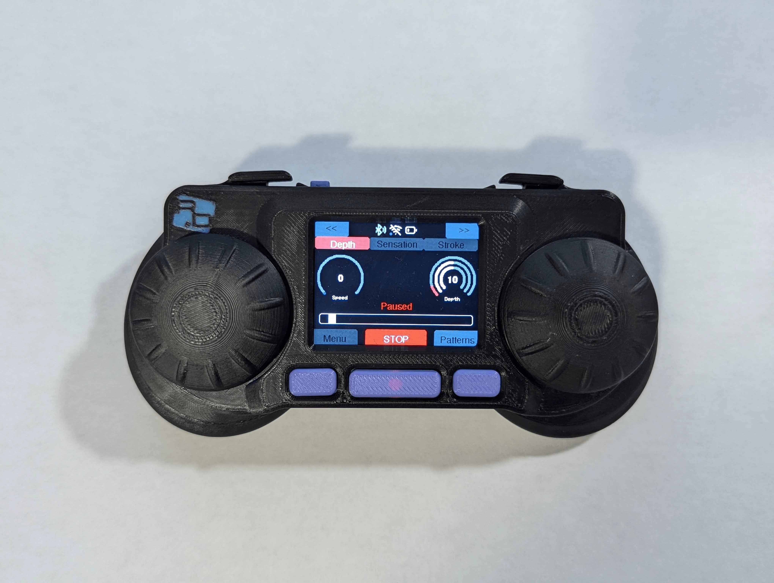
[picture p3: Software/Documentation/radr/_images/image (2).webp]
RADR play controls screen showing speed and adjustment indicators

</Frame>

| Control | Action |
|---|---|
| **Left Knob** | Adjust speed |
| **Right Knob** | Adjust current mode (Depth, Sensation, or Stroke) |
| **Left/Right Bumper** | Cycle through adjustment modes |
| **Left Button** | Open OSSM Device Settings (coming soon) |
| **Middle Button** | Single press: Pause session (increase speed to resume). Double press: Stop session and reset to defaults |
| **Right Button** | Open Pattern Mode |

## Pattern mode

<Frame>
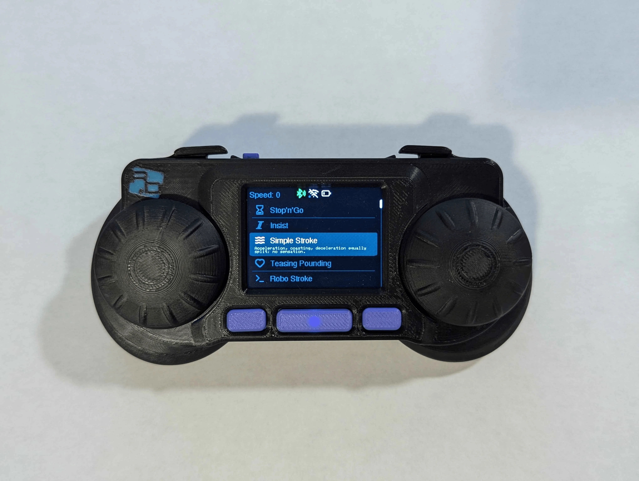
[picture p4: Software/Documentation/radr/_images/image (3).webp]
RADR pattern mode screen showing available motion patterns

</Frame>

Press the **Right Button** to enter Pattern Mode and choose from a library of built-in motion patterns.

| Control | Action |
|---|---|
| **Left Knob** | Adjust speed |
| **Right Knob** | Scroll through patterns |
| **Left/Right Bumper** | No action |
| **Left Button** | Exit to Play Controls without applying |
| **Middle Button** | Pause session and exit to Play Controls |
| **Right Button** | Select highlighted pattern |

<Tip>
More patterns are being added regularly. Check for firmware updates to access new pattern libraries.
</Tip>

## Connection recovery

If your RADR loses connection during use—whether due to distance, power loss, or Bluetooth interference—it will automatically attempt to reconnect within 2–5 seconds.

<Warning>
As a safety precaution, if the connection isn't restored quickly, the OSSM will gradually reduce speed and pause the session.
</Warning>

If reconnection fails, power-cycle both the RADR and your device. They will pair automatically when restarted.

## Next steps

Once you've completed setup:

- Your RADR is charged and paired
- Your OSSM (or other supported device) is running the latest firmware
- You can control your device wirelessly without cables or legacy displays

<CardGroup cols={2}>
<Card title="Device support" icon="bluetooth" href="./device-support">
Explore all compatible devices.
</Card>

<Card title="Firmware updates" icon="download" href="/ossm/Software/getting-started/introduction">
Keep your devices up to date.
</Card>
</CardGroup>

Enjoy your Research And Desire Wireless Remote—designed for seamless, intuitive control across the RAD ecosystem.

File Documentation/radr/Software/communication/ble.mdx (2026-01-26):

---
title: "Bluetooth Communication"
description: "BLE protocol details and device communication for RADR"
sidebarTitle: "BLE Protocol"
---

This document covers the Bluetooth Low Energy (BLE) communication protocols used by RADR to communicate with supported devices.

## BLE Overview

RADR uses Bluetooth Low Energy (BLE) for all device communication. As a BLE central device, RADR scans for and connects to peripheral devices like the OSSM and Lovense toys.

| Parameter | Value |
|---|---|
| BLE Role | Central |
| Device Name | OSSM-REMOTE |
| Transmit Power | 9 dBm |
| Stack | NimBLE |

## Scan Parameters

| Parameter | Value |
|---|---|
| Scan Interval | 100ms |
| Scan Window | 100ms |
| Scan Type | Active |
| Scan Duration | 5000ms (5 seconds) |

During active scanning, RADR sends scan request packets to devices to retrieve their full advertising data, including device names.

## Connection Parameters

RADR uses optimized connection parameters for responsive control:

| Parameter | Value | Description |
|---|---|---|
| Min Interval | 12 | 15ms minimum connection interval |
| Max Interval | 12 | 15ms maximum connection interval |
| Latency | 0 | No slave latency (immediate responses) |
| Supervision Timeout | 150 | 1500ms timeout for lost connections |
| Connect Timeout | 5000ms | Maximum time to establish connection |

The 15ms connection interval provides responsive control with minimal latency between encoder turns and device response.

## Device Discovery

RADR identifies supported devices by their advertised service UUIDs:

### Research And Desire Devices

| Device | Service UUID |
|---|---|
| OSSM | `522B443A-4F53-534D-0001-420BADBABE69` |
| LKBX | Pending implementation |
| DTT | Pending implementation |

### Lovense Devices

| Device | Service UUID |
|---|---|
| Domi 2 | `57300001-0023-4BD4-BBD5-A6920E4C5653` |
| Other | Via Buttplug.io registry |

### Buttplug.io Devices

Devices supported via the Buttplug.io protocol are identified using UUIDs from the dynamic registry (`registry.json`). This registry can be updated via firmware updates without code changes.

## OSSM Protocol

RADR communicates with OSSM using a custom BLE protocol:

### Service Structure

```
Service: 522B443A-4F53-534D-0001-420BADBABE69
├── Position Characteristic
├── Speed Characteristic
├── Depth Characteristic
├── Sensation Characteristic
├── Stroke Characteristic
└── Pattern Characteristic
```

### Command Format

Commands are sent as byte arrays to the appropriate characteristic:

| Parameter | Data Type | Range |
|---|---|---|
| Speed | uint8_t | 0-100 |
| Depth | uint8_t | 0-100 |
| Sensation | uint8_t | 0-100 |
| Stroke | uint8_t | 0-100 |
| Pattern | uint8_t | Pattern index |

### Pattern Selection

Patterns are selected by index:

| Index | Pattern Name |
|---|---|
| 0 | Simple Stroke |
| 1 | Teasing Pounding |
| 2 | Robo Stroke |
| 3 | Half'n'Half |
| 4 | Deeper |
| 5 | Stop'n'Go |
| 6 | Insist |

## Lovense Protocol

For Lovense devices with direct integration (Domi), RADR uses the Lovense BLE protocol:

### Vibration Control

```
Command: Vibrate:{level};
Level: 0-16
```

### Battery Query

```
Command: Battery;
Response: {percentage}
```

### Power Control

```
Command: PowerOff;
```

## Buttplug.io Devices

For devices supported via Buttplug.io, RADR implements a subset of the Buttplug protocol:

- **Vibrate** — Set vibration level (0-1 float, mapped to device range)
- **Linear** — For thrusting devices
- **Rotate** — For rotating devices

Not all devices support all commands. RADR queries device capabilities during connection.

## Connection Recovery

If RADR loses connection to a device:

1. **Detection** — Connection loss detected within supervision timeout (1500ms)
2. **Reconnection** — Automatic reconnection attempt within 2-5 seconds
3. **Safety** — For OSSM, gradual ramp-down during disconnection
4. **Failure** — After failed reconnection, return to main menu

## Security

RADR uses open BLE connections without pairing or bonding:

- No PIN required
- No encryption (commands are plaintext)
- Single connection at a time

<Warning>
BLE communications are not encrypted. Use RADR in private settings where radio interception is not a concern.
</Warning>

## Debugging

For BLE debugging during development:

1. Use a BLE sniffer (nRF Connect, Wireshark with BLE adapter)
2. Enable serial logging in firmware (`LOG_LEVEL_DEBUG`)
3. Monitor connection events and characteristic writes

## Further Reading

<CardGroup cols={2}>
<Card title="NimBLE Documentation" icon="book" href="https://mynewt.apache.org/latest/network/index.html">
NimBLE stack documentation.
</Card>

<Card title="Buttplug.io Protocol" icon="book" href="https://buttplug-spec.docs.buttplug.io/">
Buttplug device protocol specification.
</Card>
</CardGroup>

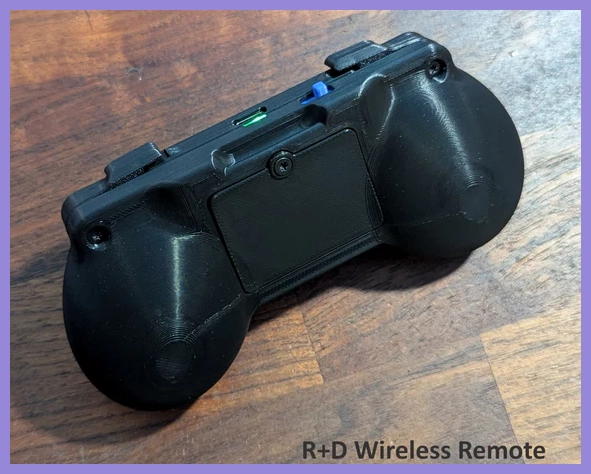
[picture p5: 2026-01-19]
Hardware/Photos/RADR Rear.webp

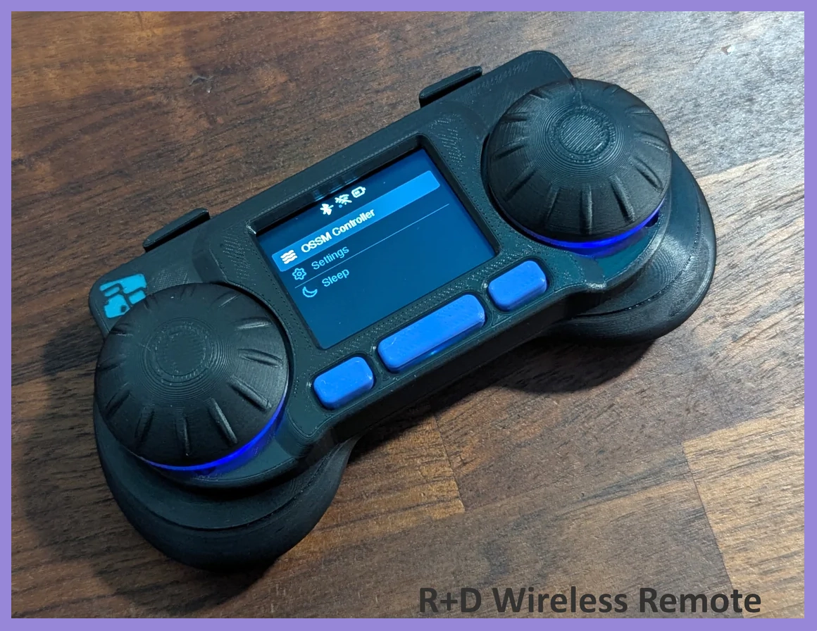
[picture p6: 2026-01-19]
Hardware/Photos/RADR main menu.webp

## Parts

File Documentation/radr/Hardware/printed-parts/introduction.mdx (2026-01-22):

---
title: "Printed Parts"
description: "3D printing guide for RADR enclosure and components"
sidebarTitle: "Introduction"
---

This guide covers the 3D printed parts required to build a RADR wireless remote.

## Required Parts

| Part | Quantity | Notes |
|---|---|---|
| Top Housing | 1 | Main body with display cutout |
| Bottom Housing | 1 | Battery compartment and mounting |
| Buttons | 3 | Under-screen buttons |
| Encoder Knobs | 2 | Left and right encoder caps |
| Power Switch Cap | 1 | Optional cover for power switch |

## Print Settings

These parts print nicely with the following settings:

| Parameter | Recommended Value |
|---|---|
| Layer Height | 0.12mm (for smooth curves) |
| Wall Thickness | 4 layers |
| Infill | 20-30% |
| Material | PLA, PETG, or ASA |

<Tip>
Using your slicer's auto layer height function will balance resolution and speed.
</Tip>

### Top Housing

The top housing requires significant supports due to the display cutout and internal features.

- Print with the display opening facing up
- Enable supports for overhangs
- For Bambu printers, the included 3mf file has recommended support settings

### Remote Clip (Optional)

If you're printing the wireless remote clip for mounting:

| Parameter | Recommended Value |
|---|---|
| Wall Thickness | 6 layers |
| Infill | 40%+ |

The clip needs extra strength to handle repeated mounting and removal.

## Multi-Color Printing

Many of these parts contain multiple bodies to allow multi-color printing. This is optional—you can print all as the same color if you don't need to see the LEDs through the housing.

### Transparent Sections

The following areas benefit from transparent or translucent filament:

| Area | Purpose |
|---|---|
| Power indicator | Shows charging LED |
| Button status indicators | Shows button backlighting |
| Knob backlight areas | Shows encoder LED colors |

<Info>
Multi-color printing is purely aesthetic. The device functions identically with single-color prints.
</Info>

## Part-by-Part Guides

Detailed documentation for each printed component with 3D preview, print settings, and assembly instructions:

<CardGroup cols={2}>
<Card title="Top Housing" icon="cube" href="/radr/Hardware/printed-parts/part-by-part/remote-top">
  Main body with display cutout
</Card>
<Card title="Bottom Housing" icon="cube" href="/radr/Hardware/printed-parts/part-by-part/remote-bottom">
  Battery compartment and mounting
</Card>
<Card title="Encoder Knobs" icon="circle-dot" href="/radr/Hardware/printed-parts/part-by-part/remote-knob">
  Press-fit caps for rotary encoders
</Card>
<Card title="Buttons" icon="hand-pointer" href="/radr/Hardware/printed-parts/part-by-part/buttons">
  Under-screen tactile button caps
</Card>
<Card title="Power Switch Cap" icon="power-off" href="/radr/Hardware/printed-parts/part-by-part/power-switch">
  Optional cover for power switch
</Card>
<Card title="OSSM Remote Clip" icon="link" href="/radr/Hardware/printed-parts/part-by-part/ossm-remote-clip">
  Mount the remote to OSSM extrusion
</Card>
</CardGroup>

## Source Files

All print files are available on GitHub:

<Card title="Print Files" icon="cube" href="https://github.com/researchanddesire/radr-wireless-remote/tree/main/Hardware/Print%20Files">
Download STEP and 3MF files.
</Card>

### Available Formats

| Format | Description |
|---|---|
| .3mf | Bambu Studio project with print settings |
| .step | Editable CAD format for modifications |
| .stl | Standard mesh format for any slicer |

## Assembly Tips

<Tip>
Test fit all parts before final assembly. Some printer calibration variation may require light sanding.
</Tip>

<Tip>
The encoder knobs press-fit onto the encoder shafts. Apply even pressure when installing.
</Tip>

<Warning>
Don't over-tighten screws into 3D printed parts. The threads can strip if overtightened.
</Warning>

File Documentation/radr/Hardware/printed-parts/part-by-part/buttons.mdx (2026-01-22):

---
title: "Buttons"
description: "Under-screen tactile button caps for the RADR wireless remote"
---

import { STLViewer } from '/snippets/ossm/stl-render.jsx';

<STLViewer url="https://raw.githubusercontent.com/researchanddesire/radr-wireless-remote/main/Hardware/Print%20Files/Buttons.stl" />

## Function

The Buttons are small caps that sit over the tactile switches beneath the display. This component:

- Provides a comfortable press surface for the three under-screen buttons
- Transfers actuation force to the underlying tactile switches
- Features optional translucent sections for LED status indicators
- Three buttons required per remote

## Print Settings

| Setting | Value |
|---|---|
| Layer Height | 0.12mm |
| Walls | 4 |
| Infill Type | Gyroid |
| Infill Percentage | 30% |
| Supports | Minimal or none |

<Tip>
These are small parts. Use a brim for bed adhesion if needed, and print multiple at once for efficiency.
</Tip>

## Multi-Color Printing (Optional)

The buttons include a separate body for the LED indicator area:

| Area | Purpose | Recommended Material |
|---|---|---|
| Indicator window | Shows button status LED | Transparent/translucent |
| Button face | Press surface | Any opaque color |

<Info>
Multi-color printing is optional. Single-color buttons work perfectly—you just won't see the status LEDs through the button caps.
</Info>

## Installation

<Steps>
<Step title="Print three buttons">
  Print all three button caps using the settings above.

  <Check>
  Buttons are free of stringing and have clean surfaces.
  </Check>
</Step>

<Step title="Test fit">
  Place each button into its housing slot in the top enclosure. They should move freely up and down.

  <Warning>
  If buttons bind or stick, lightly sand the sides. Do not force them into place.
  </Warning>
</Step>

<Step title="Verify actuation">
  With the PCB installed, press each button to confirm it properly actuates the underlying switch.

  <Check>
  Each button clicks cleanly and springs back when released.
  </Check>
</Step>
</Steps>

## Download Files

<CardGroup cols={2}>
<Card title="STEP File" icon="cube" href="https://github.com/researchanddesire/radr-wireless-remote/blob/main/Hardware/Print%20Files/Buttons.step">
  Download for CAD editing
</Card>
<Card title="3MF Project" icon="layer-group" href="https://github.com/researchanddesire/radr-wireless-remote/blob/main/Hardware/Print%20Files/Bambu%20A1%20Remote_V1.01.3mf">
  Bambu Studio project with print settings
</Card>
</CardGroup>

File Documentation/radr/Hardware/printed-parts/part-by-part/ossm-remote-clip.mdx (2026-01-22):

---
title: "OSSM Remote Clip"
description: "Mounting clip to attach the RADR wireless remote to an OSSM extrusion frame"
---

import { STLViewer } from '/snippets/ossm/stl-render.jsx';

<STLViewer url="https://raw.githubusercontent.com/researchanddesire/radr-wireless-remote/main/Hardware/Print%20Files/OSSM%20Remote%20Clip%20-%20Extrusion%20Bottom%20Release%20(M6x12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" />

## Function

The OSSM Remote Clip allows you to mount the RADR wireless remote directly onto an OSSM aluminum extrusion frame. This component:

- Clips onto standard 2020/2040 aluminum extrusion profiles
- Provides a secure, removable mount for the remote
- Features a bottom-release mechanism for easy attachment/detachment
- Requires an M6x12 bolt for the clamping mechanism

## Print Settings

| Setting | Value |
|---|---|
| Layer Height | 0.16mm |
| Walls | 6 |
| Infill Type | Gyroid or Grid |
| Infill Percentage | 40%+ |
| Supports | Yes - Auto |

<Warning>
This part needs extra strength to handle repeated mounting and removal. Use more walls and higher infill than other parts.
</Warning>

<Tip>
PETG or ABS is recommended over PLA for better durability and fatigue resistance.
</Tip>

## Hardware Required

| Item | Quantity | Notes |
|---|---|---|
| M6x12mm bolt | 1 | Socket head or button head |
| M6 nut (optional) | 1 | Depending on clip design variant |

## Installation

<Steps>
<Step title="Print the clip">
  Print with increased wall count and infill for durability.

  <Check>
  The clip is solid with no visible layer separation or weak spots.
  </Check>
</Step>

<Step title="Insert hardware">
  Thread the M6x12 bolt into the clip's clamping mechanism.

  <Tip>
  If threads are tight, run the bolt in and out a few times to clean them, or chase with an M6 tap.
  </Tip>
</Step>

<Step title="Mount to extrusion">
  Position the clip on the aluminum extrusion and tighten the bolt to clamp it in place.

  <Warning>
  Don't overtighten—the plastic can crack. Tighten until secure, then stop.
  </Warning>
</Step>

<Step title="Attach remote">
  Slide or clip the RADR remote into the mounted clip.

  <Check>
  Remote is secure and doesn't wobble or fall out during use.
  </Check>
</Step>
</Steps>

## Troubleshooting

<AccordionGroup>
<Accordion title="Clip doesn't fit extrusion snugly">
- Check that you're using standard 2020 or 2040 aluminum extrusion.
- Some printer tolerances may require scaling the model by ±1%.
- Lightly sand the inside surfaces for a better fit.
</Accordion>

<Accordion title="Clip cracks when tightening">
- Reduce clamping force.
- Reprint with more walls (8+) and higher infill (50%+).
- Use PETG or ABS instead of PLA.
</Accordion>

<Accordion title="Bolt threads strip">
- Use a metal M6 nut embedded in the clip (heat-set insert or press-fit).
- Chase threads with an M6 tap before use.
- Print with finer layer height for better thread definition.
</Accordion>
</AccordionGroup>

## Download Files

<Card title="STEP File" icon="cube" href="https://github.com/researchanddesire/radr-wireless-remote/blob/main/Hardware/Print%20Files/OSSM%20Remote%20Clip%20-%20Extrusion%20Bottom%20Release%20(M6x12).step">
  Download for CAD editing
</Card>

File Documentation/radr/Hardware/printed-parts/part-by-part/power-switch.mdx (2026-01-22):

---
title: "Power Switch Cap"
description: "Optional decorative cover for the RADR wireless remote power switch"
---

import { STLViewer } from '/snippets/ossm/stl-render.jsx';

<STLViewer url="https://raw.githubusercontent.com/researchanddesire/radr-wireless-remote/main/Hardware/Print%20Files/Power%20Switch.stl" />

## Function

The Power Switch Cap is an optional decorative cover that fits over the power switch toggle. This component:

- Provides an aesthetically finished look to the power switch
- Sits over the existing switch toggle
- Purely cosmetic—not required for operation

## Print Settings

| Setting | Value |
|---|---|
| Layer Height | 0.12mm |
| Walls | 4 |
| Infill Type | Gyroid |
| Infill Percentage | 25% |
| Supports | None |

<Tip>
This is a very small part. Print multiple copies or include it with other small parts like the buttons for efficiency.
</Tip>

## Installation

<Steps>
<Step title="Print the cap">
  Print the power switch cap using the settings above.

  <Check>
  The cap is free of defects and has clean surfaces.
  </Check>
</Step>

<Step title="Press onto switch">
  Gently press the cap onto the power switch toggle. It should friction-fit in place.

  <Warning>
  Do not use adhesive unless the fit is too loose. A drop of CA glue can be used as a last resort.
  </Warning>
</Step>

<Step title="Test operation">
  Verify the switch still operates smoothly with the cap installed.

  <Check>
  Switch toggles on/off with no binding or interference.
  </Check>
</Step>
</Steps>

<Info>
This part is optional. The remote functions perfectly without it—the power switch is fully usable as-is.
</Info>

## Download Files

<CardGroup cols={2}>
<Card title="STEP File" icon="cube" href="https://github.com/researchanddesire/radr-wireless-remote/blob/main/Hardware/Print%20Files/Power%20Switch.step">
  Download for CAD editing
</Card>
<Card title="3MF Project" icon="layer-group" href="https://github.com/researchanddesire/radr-wireless-remote/blob/main/Hardware/Print%20Files/Bambu%20A1%20Remote_V1.01.3mf">
  Bambu Studio project with print settings
</Card>
</CardGroup>

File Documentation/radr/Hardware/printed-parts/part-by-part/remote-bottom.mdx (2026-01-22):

---
title: "Remote - Bottom Housing"
description: "The lower enclosure for the RADR wireless remote containing the battery compartment"
---

import { STLViewer } from '/snippets/ossm/stl-render.jsx';

<STLViewer url="https://raw.githubusercontent.com/researchanddesire/radr-wireless-remote/main/Hardware/Print%20Files/Remote%20-%20Bottom.stl" />

## Function

The Bottom Housing is the lower shell of the RADR wireless remote. This component:

- Forms the battery compartment for the rechargeable battery
- Provides the rear ergonomic surface for comfortable grip
- Contains mounting bosses for PCB attachment
- Features the USB-C charging port access
- Mates with the Top Housing to complete the enclosure

## Print Settings

| Setting | Value |
|---|---|
| Layer Height | 0.12mm (for smooth curves) |
| Walls | 4 |
| Infill Type | Gyroid |
| Infill Percentage | 20-30% |
| Supports | Yes - for internal features |

<Tip>
Print with the interior facing up to ensure clean exterior surfaces.
</Tip>

## Assembly Notes

<Steps>
<Step title="Check fit">
  Test fit the PCB and battery before final assembly. Verify the USB-C port aligns with the housing opening.
  
  <Check>
  The PCB sits flat on the mounting bosses with no interference.
  </Check>
</Step>

<Step title="Verify clearances">
  Ensure the battery fits with adequate clearance. Some printer tolerances may require light sanding.
  
  <Warning>
  Do not force components. If fit is too tight, sand lightly rather than applying excessive force.
  </Warning>
</Step>
</Steps>

## Download Files

<CardGroup cols={2}>
<Card title="STEP File" icon="cube" href="https://github.com/researchanddesire/radr-wireless-remote/blob/main/Hardware/Print%20Files/Remote%20-%20Bottom.step">
  Download for CAD editing
</Card>
<Card title="3MF Project" icon="layer-group" href="https://github.com/researchanddesire/radr-wireless-remote/blob/main/Hardware/Print%20Files/Bambu%20A1%20Remote_V1.01.3mf">
  Bambu Studio project with print settings
</Card>
</CardGroup>

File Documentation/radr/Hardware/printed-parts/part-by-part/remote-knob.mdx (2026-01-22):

---
title: "Remote - Encoder Knob"
description: "Press-fit knobs for the RADR wireless remote rotary encoders"
---

import { STLViewer } from '/snippets/ossm/stl-render.jsx';

<STLViewer url="https://raw.githubusercontent.com/researchanddesire/radr-wireless-remote/main/Hardware/Print%20Files/Remote%20-%20Knob.stl" />

## Function

The Encoder Knobs are press-fit caps for the RADR wireless remote's rotary encoders. This component:

- Provides an ergonomic grip surface for encoder control
- Press-fits onto the encoder shafts
- Features optional translucent sections for LED backlighting
- Two knobs required per remote (left and right encoders)

## Print Settings

| Setting | Value |
|---|---|
| Layer Height | 0.12mm |
| Walls | 4 |
| Infill Type | Gyroid |
| Infill Percentage | 25% |
| Supports | Yes - Auto |

<Tip>
Print with the shaft cavity facing upward for best surface quality inside the bore.
</Tip>

## Multi-Color Printing (Optional)

The knobs include a separate body for the backlight ring area:

| Area | Purpose | Recommended Material |
|---|---|---|
| Backlight ring | Shows encoder LED colors | Transparent/translucent |
| Main body | Grip surface | Any opaque color |

## Installation

<Steps>
<Step title="Prepare the part">
  Remove supports and lightly deburr the bore with a hobby knife or small round file.

  <Check>
  The bore is clean and smooth; no support material remains inside.
  </Check>
</Step>

<Step title="Test fit on the encoder shaft">
  Align the knob with the encoder shaft. Do not force it—ensure alignment first.

  <Warning>
  Excessive force can damage the encoder. Apply steady, straight pressure only.
  </Warning>
</Step>

<Step title="Press-fit the knob">
  Press straight down until fully seated. Repeat for the second encoder.

  <Check>
  Knobs rotate smoothly and the remote registers encoder turns and clicks.
  </Check>
</Step>
</Steps>

## Troubleshooting

<AccordionGroup>
<Accordion title="Fit is too tight">
- Lightly ream the bore with a small round file or deburring tool.
- Re-slice with −0.5% to −1% XY scale or use a negative horizontal expansion value.
- Warm the knob slightly (hair dryer) and press-fit while warm.
</Accordion>

<Accordion title="Fit is too loose">
- Re-slice with +0.5% to +1% XY scale.
- Add a thin wrap of PTFE/plumber's tape to the shaft as a temporary shim.
</Accordion>

<Accordion title="Support marks inside the bore">
- Increase support Z-distance/interface layers.
- Switch to tree supports or reduce support density.
- Orient with the bore up to minimize internal supports.
</Accordion>
</AccordionGroup>

## Download Files

<CardGroup cols={2}>
<Card title="STEP File" icon="cube" href="https://github.com/researchanddesire/radr-wireless-remote/blob/main/Hardware/Print%20Files/Remote%20-%20Knob.step">
  Download for CAD editing
</Card>
<Card title="3MF Project" icon="layer-group" href="https://github.com/researchanddesire/radr-wireless-remote/blob/main/Hardware/Print%20Files/Bambu%20A1%20Remote_V1.01.3mf">
  Bambu Studio project with print settings
</Card>
</CardGroup>

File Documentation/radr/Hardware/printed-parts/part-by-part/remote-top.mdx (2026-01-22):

---
title: "Remote - Top Housing"
description: "The main top enclosure for the RADR wireless remote with display cutout and button openings"
---

import { STLViewer } from '/snippets/ossm/stl-render.jsx';

<STLViewer url="https://raw.githubusercontent.com/researchanddesire/radr-wireless-remote/main/Hardware/Print%20Files/Remote%20-%20Top%20V1.01.stl" />

## Function

The Top Housing is the main upper shell of the RADR wireless remote. This component:

- Houses the TFT display with a precision cutout for the screen
- Provides openings for the three tactile buttons
- Features mounting points for the rotary encoders (knobs)
- Contains windows for LED status indicators (optional transparent sections)
- Defines the primary ergonomic grip surface

## Print Settings

| Setting | Value |
|---|---|
| Layer Height | 0.12mm (for smooth curves) |
| Walls | 4 |
| Infill Type | Gyroid |
| Infill Percentage | 20-30% |
| Supports | Yes - significant supports needed |

<Note>
The display cutout and internal features require substantial support material. For Bambu printers, the included 3MF file has optimized support settings.
</Note>

<Tip>
Print with the display opening facing up for best results on the visible surfaces.
</Tip>

## Multi-Color Printing (Optional)

The top housing includes separate bodies for multi-color printing:

| Area | Purpose | Recommended Material |
|---|---|---|
| Power indicator window | Shows charging LED | Transparent/translucent |
| Button status windows | Shows button backlighting | Transparent/translucent |
| Knob backlight rings | Shows encoder LED colors | Transparent/translucent |

<Info>
Multi-color printing is purely aesthetic. The remote functions identically with single-color prints.
</Info>

## Download Files

<CardGroup cols={2}>
<Card title="STEP File" icon="cube" href="https://github.com/researchanddesire/radr-wireless-remote/blob/main/Hardware/Print%20Files/Remote%20-%20Top%20V1.01.step">
  Download for CAD editing
</Card>
<Card title="3MF Project" icon="layer-group" href="https://github.com/researchanddesire/radr-wireless-remote/blob/main/Hardware/Print%20Files/Bambu%20A1%20Remote_V1.01.3mf">
  Bambu Studio project with print settings
</Card>
</CardGroup>

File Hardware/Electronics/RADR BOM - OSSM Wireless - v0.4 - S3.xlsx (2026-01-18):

Quantity | Designator | Footprint | Value | Manufacturer Part | Manufacturer
1 | Blue_Charge | LED-SMD_L1.7-W0.6-RD |  | TJ-S1706SW6TGLC6B-A5 | TOGIALED(统佳)
1 | BUZZER1 | BUZ-SMD_L4.0-W4.0-P3.50-L | 4kHz | FUET-4020 | FUET(福声科技)
7 | C6,C8,C23,C24,C25,C26,C35 | C0402 | 10uF | GRM155R61A106ME44D | muRata(村田)
5 | C9,C11,C15,C16,C17 | C0402 | 100nF | CL05A104KA5NNNC | SAMSUNG(三星)
2 | C10,C27 | C0402 | 1uF | CL05A105KA5NQNC | SAMSUNG(三星)
1 | C14 | C0402 | 10uF | CL05A106MP5NUNC | SAMSUNG(三星)
3 | C18,C19,C20 | C0402 | 2.2uF | CL05A225KO5NQNC | SAMSUNG(三星)
5 | C28,C29,C30,C32,C33 | C1206 | 100uF | GRM31CR60J107ME39L | muRata(村田)
1 | C34 | C0402 | 10nF | CC0402KRX7R5BB103 | YAGEO(国巨)
2 | D1,D2 | SOD-123F_L2.7-W1.6-LS3.8-RD-1 |  | B5819W | GOODWORK(固得沃克)
1 | D3 | SOD-123_L2.8-W1.8-LS3.7-RD |  | B5819W-TP | MCC(美微科)
2 | ENC_L,ENC_R | SW-TH_EC12EXXXX |  | EC12E24204A8 | ALPSALPINE(阿尔卑斯阿尔派)
3 | ESP,External,Internal | SOT-23-5_L3.0-W1.7-P0.95-LS2.8-BL |  | ME6211C33M5G-N | MICRONE(南京微盟)
1 | Green_Power | LED-SMD_L1.7-W0.6-RD |  | TJ-S1706SW6TGLC2G-A5 | TOGIALED(统佳)
5 | LS_1,LS_2,RESET,RS_1,RS_2 | SW-SMD_TS24CA |  | TS24CA | SHOU HAN(首韩)
1 | M1 | VIBRATING-MOTOR-SMD_3P-C9900001680 |  | Z3OC1T8219731 | KOTL(金龙机电)
2 | P-UP-1,P-UP-2 | SW-SMD_2P-L6.2-W2.5-LS9.4 |  | 2.54-1P TPGT | SHOU HAN(首韩)
1 | POWERSW | SW-TH_SK12D07VG5 |  | SK12D07VG5 | SHOU HAN(首韩)
3 | Q1,Q2,Q3 | SOT-23_L2.9-W1.3-P1.90-LS2.4-BR |  | AO3400 | GOODWORK(固得沃克)
2 | Q5,Q6 | SOT-23-3_L2.9-W1.3-P1.90-LS2.4-BR |  | BC817 | CJ（江苏长电/长晶）
1 | Q7 | SOT-23-3_L2.9-W1.4-P1.91-LS2.6-BR |  | SI2301 | TWGMC(台湾迪嘉)
1 | QWIIC | CONN-SMD_4P-P1.00_SM04B-SRSS-TB-LF-SN |  | SM04B-SRSS-TB(LF)(SN) | JST
1 | R1 | R0603 | 10Ω | PS03W4F100JT5E | UNI-ROYAL(厚声)
3 | R7,R8,R26 | R0402 | 10kΩ | WR04X1002FTL | 华新科(Walsin)
2 | R9,R10 | R0402 | 100Ω | RC0402FR-07100RL | YAGEO(国巨)
2 | R11,R16 | R0402 | 1kΩ | RC0402FR-071KL | YAGEO(国巨)
1 | R18 | R0402 | 2kΩ | RC0402FR-072KL | YAGEO(国巨)
1 | R19 | R0402 | 330Ω | RC0402FR-07330RL | YAGEO(国巨)
2 | R20,R21 | R0402 | 5.1kΩ | 0402WGF5101TCE | UNI-ROYAL(厚声)
8 | R22,R23,R24,R25,R32,R35,R36,R39 | R0402 | 10kΩ | RC0402FR-0710KL | YAGEO(国巨)
1 | R34 | R0402 | 5.1kΩ | RC0402FR-075K1L | YAGEO(国巨)
2 | R40,R41 | R0402 | 4.7kΩ | 0402WGJ0472TCE | UNI-ROYAL(厚声)
1 | SCREEN | FPC-SMD_AFC01-S14FCA-00 |  | AFC01-S14FCA-00 | JS(钜硕电子)
3 | U1,U2,U3 | LED-SMD_4P-L1.0-W1.0-TL_XL-1010RGBC-WS2812B |  | XL-1010RGBC-WS2812B | XINGLIGHT(成兴光)
1 | U5 | LGA-14_L3.0-W2.5-P0.50-TL |  | LSM6DS3TR-C | ST(意法半导体)
1 | U6 | SOT-23-5_L3.0-W1.7-P0.95-LS2.8-BL |  | TP4054-42-SOT25R | TOPPOWER(南京拓微)
1 | U8 | CONN-TH_S2B-PH-K-LF-SN |  | S2B-PH-K(LF)(SN) | JST
1 | U9 | WQFN-28_L5.0-W5.0-P0.50-BL-EP3.2 |  | CP2102-GMR | SILICON LABS(芯科)
1 | U14 | DFN-8_L2.0-W2.0-P0.50-BL-EP |  | MAX17048G+T10 | ADI(亚德诺)/MAXIM(美信)
1 | U15 | WIRELM-SMD_ESP32-S3-WROOM-1 |  | ESP32-S3-WROOM-1-N16R8 | ESPRESSIF(乐鑫)
1 | U16 | SOIC-8_L5.0-W4.0-P1.27-LS6.0-BL |  | AT24C04C-SSHM-T | MICROCHIP(美国微芯)
1 | USBC1 | USB-C_SMD-TYPE-C-31-M-12 |  | TYPE-C-31-M-12 | 韩国韩荣
4 | US_L,US_M_1,US_M_2,US_R | SW-TH_4P-L5.0-W5.0-P4.50-LS6.5 |  | TC-6610-9-260G | HCTL(华灿天禄)

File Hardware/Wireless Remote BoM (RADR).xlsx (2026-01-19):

Part | QTY | Part number
Hardware
Tri lobe screws | 5 | 0408LTFB
Screen | 1 | IPS 2.0 inch 14PIN SPI LCD Display ST7789 240(RGB)*320
Battery | 1 | 3.7V 800mAh Lipo 802735
PCB | 1 | RADR-PCB-V0.4
Printed
Front housing | 1
Back housing | 1
Battery flap | 1
Side button | 2
Middle button | 1
Power slider button | 1
Knobs | 2

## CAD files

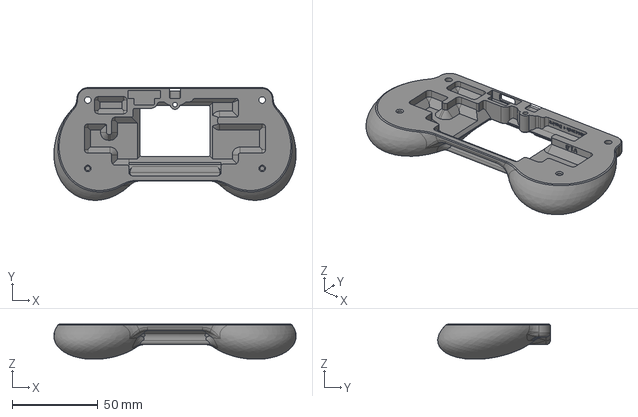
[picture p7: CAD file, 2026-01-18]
Hardware/Print Files/Remote - Bottom.step
141.5 x 65.9 x 20.2 mm
ChargePower Light
Rear

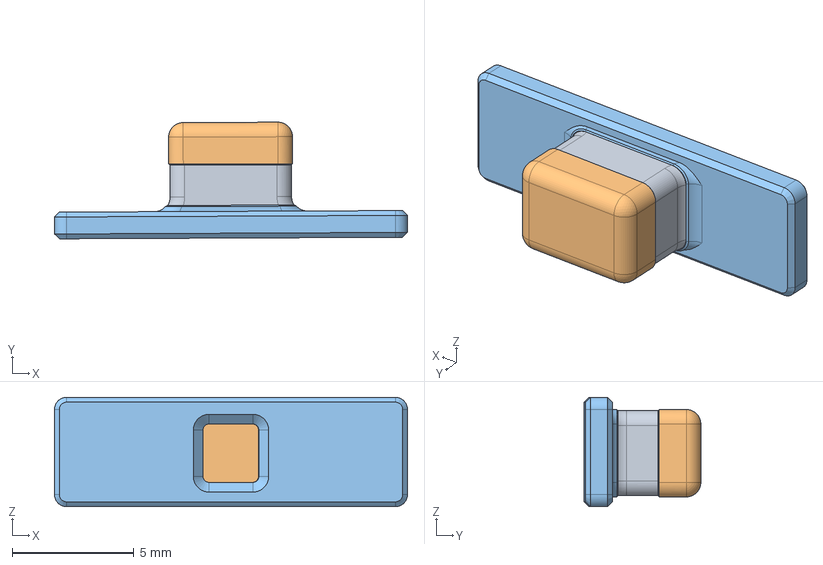
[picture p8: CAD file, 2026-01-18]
Hardware/Print Files/Power Switch.step
14.5 x 4.80 x 4.50 mm

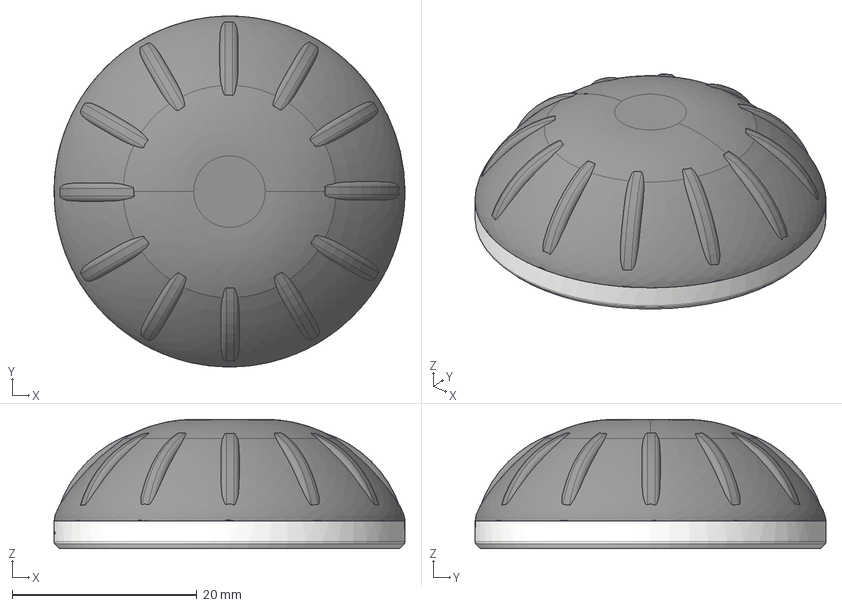
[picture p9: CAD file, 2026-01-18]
Hardware/Print Files/Remote - Knob.step
38.0 x 38.0 x 14.0 mm
Knurling
Clear Base
Upper

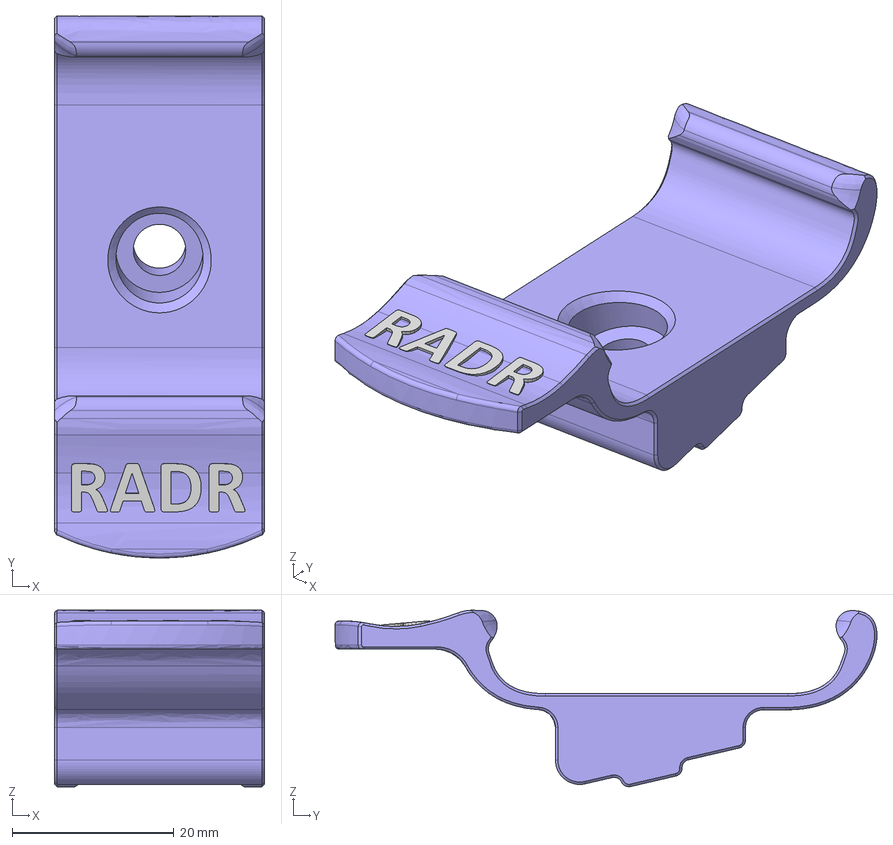
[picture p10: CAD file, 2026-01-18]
Hardware/Print Files/OSSM Remote Clip - Extrusion Bottom Release (M6x12).step
26.0 x 67.0 x 21.8 mm

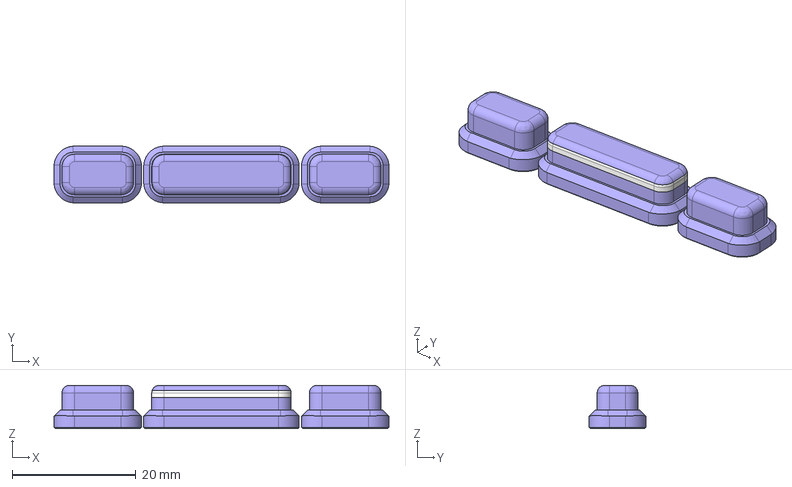
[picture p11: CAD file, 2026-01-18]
Hardware/Print Files/Buttons.step
54.2 x 9.16 x 7.00 mm
Center
Clear
Button - LeftRight x 2

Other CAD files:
Hardware/Print Files/Buttons.stl
Hardware/Print Files/OSSM Remote Clip - Extrusion Bottom Release (M6x12).stl
Hardware/Print Files/Power Switch.stl
Hardware/Print Files/Remote - Bottom.stl
Hardware/Print Files/Remote - Knob.stl

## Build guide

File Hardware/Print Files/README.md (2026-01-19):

## Print Guidance

### Print Settings
These parts print nicely at 4 layer wall thickness and 0.12mm layer height for smooth curves. Using your slicer's auto layer height function will balance resolution and speed.
The top housing needs significant supports, and the 3mf file gives my recommended settings for Bambu printers.
If you are printing the wireless remote clip - I would recommend 6 walls and just make it extra solid.

### Multi Color
Many of these parts contain multiple bodies to allow multi color printing. This is optional and you can simply print all as the same color if you don't need to see the LEDs. 
There are clear section for
* Power indicator
* Button statuts indicators
* Knob backlight and status

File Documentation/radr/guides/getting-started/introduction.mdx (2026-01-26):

---
title: "Introduction"
description: "Welcome to RADR, the open-source wireless remote controller for the OSSM and Bluetooth-enabled devices."
---

## What is RADR?

{/* TODO: */}
**RADR** (pronounced like "radar") is a user-friendly, everyday wireless controller for sex machines and Bluetooth toys. Originally designed to control the [Open Source Sex Machine (OSSM)](/ossm/guides/getting-started/introduction), RADR has evolved into a versatile controller supporting a wide range of Bluetooth-enabled devices through the [Buttplug.io](https://buttplug.io/) protocol.

<Frame>
RADR wireless remote controller
</Frame>

## Key Features

<CardGroup cols={2}>
<Card title="Wireless Control" icon="signal-stream">
Bluetooth Low Energy (BLE) connectivity with automatic device discovery and pairing.
</Card>

<Card title="Multi-Device Support" icon="bluetooth">
Control OSSM, Lovense toys, and hundreds of other devices via Buttplug.io.
</Card>

<Card title="Intuitive Interface" icon="hand-pointer">
Two rotary encoders, three buttons, and bumpers for eyes-free operation.
</Card>

<Card title="Full-Color Display" icon="display">
320x240 TFT LCD shows all settings, battery status, and device information.
</Card>

<Card title="4+ Hour Battery" icon="battery-full">
Built-in lithium battery with USB-C charging and intelligent power management.
</Card>

<Card title="Open Source" icon="code-branch">
Fully open hardware and software under the CERN OHL-S v2 license.
</Card>
</CardGroup>

## Design Philosophy

RADR was created with these principles in mind:

1. **Simplicity** — Control your devices without reaching for a phone or computer
2. **Reliability** — Direct Bluetooth connection without cloud dependencies
3. **Tactile Feedback** — Operate by feel with physical knobs and buttons
4. **Openness** — Community-driven development and full source availability

## Getting Started

If you're new to RADR, start here:

<CardGroup cols={2}>
<Card title="Quick Start" icon="rocket" href="./quick-start">
Get your RADR set up and paired in minutes.
</Card>

<Card title="Device Support" icon="list-check" href="../reference/device-support">
See which devices work with RADR.
</Card>
</CardGroup>

## What's in the Box

If you purchased a complete RADR from Research And Desire:

- RADR wireless remote
- USB-C charging cable

You'll need to provide:

- A compatible device (OSSM, Lovense toy, etc.)
- A USB power source for charging

## Building Your Own

RADR is open-source hardware. You can build your own using:

- [PCB Design Files](https://github.com/researchanddesire/radr-wireless-remote/tree/main/Hardware/Electronics) — Altium design files and schematics
- [3D Print Files](https://github.com/researchanddesire/radr-wireless-remote/tree/main/Hardware/Print%20Files) — STL and STEP files for the enclosure
- [Bill of Materials](https://github.com/researchanddesire/radr-wireless-remote/tree/main/Hardware) — Complete parts list
- [Firmware Source](https://github.com/researchanddesire/radr-wireless-remote/tree/main/Software) — ESP32 firmware

<Card title="Hardware Documentation" icon="screwdriver-wrench" href="/radr/Hardware/getting-started/introduction">
Technical documentation for building RADR.
</Card>

## Community

Join the Kinky Makers community to share your builds, get help, and contribute to development:

<DiscordInvite community="kinky-makers" />

## Next Steps

<CardGroup cols={2}>
<Card title="Quick Start Guide" icon="play" href="./quick-start">
Get up and running with RADR.
</Card>

<Card title="User Guides" icon="book" href="../user-guide/introduction">
Learn all the controls and features.
</Card>

<Card title="Technical Specs" icon="microchip" href="/radr/Hardware/getting-started/introduction">
Explore the hardware specifications.
</Card>

<Card title="Open Source" icon="code" href="../housekeeping/open-source/introduction">
Learn about RADR's open-source licensing.
</Card>
</CardGroup>

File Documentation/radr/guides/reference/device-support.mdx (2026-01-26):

---
title: "Device Support"
description: "Complete list of devices officially supported by the Research And Desire Wireless Remote (RADR)"
---

## Overview

RADR supports Research And Desire devices first, followed by popular third‑party toys via direct integrations and the Buttplug.io Bluetooth protocol. We continuously evaluate, implement, and validate support across 2025–2026.

<Info>
Want us to prioritize a device or add a new one? Email support@researchanddesire.com or use our contact form at https://www.researchanddesire.com/contact.
</Info>

### Status legend

- Supported: RADR can connect and control the device.
- Tested: Verified by R+D in-house for reliability with RADR.
- Vibration Only: Only the vibration motor is controllable; advanced features (heating, thrusting, suction, rotation, lighting) are not yet supported.
- Oscillation Only: Only oscillation/thrusting control is available; vibration features are not supported.
- Pending: Not yet implemented; on the roadmap.

<Tip>
For the smoothest setup, keep your device firmware up to date and follow the <a href="../getting-started/quick-start">Quick Start</a> to pair.
</Tip>

<Info>
Device support is continuously expanding. RADR uses a dynamic device registry that can be updated via firmware updates without changing the core application, allowing new devices to be added more frequently.
</Info>

<Warning>
Untested devices show a warning before first use. When connecting to an untested device for the first time, RADR displays a confirmation dialog. You must acknowledge you understand the risks before proceeding. Start at the lowest intensity and verify basic controls before a session.
</Warning>

## Verify your device works with RADR

<Steps>
<Step title="Charge and update">
Charge your RADR via USB‑C. If your OSSM or RADR needs an update, flash using the <a href="/ossm/guides/getting-started/web-flasher">Web Flasher</a>.

<Check>
Device powers on and shows the home screen.
</Check>
</Step>

<Step title="Power on and make discoverable">
Turn on your target device and ensure Bluetooth is enabled or the device is in pairing/advertising mode (consult the device's manual if unsure).
</Step>

<Step title="Scan with RADR">
Follow the <a href="../getting-started/quick-start">Quick Start</a> to scan. RADR only lists supported devices; if yours appears, select to connect.

<Check>
You can start/stop and change intensity from RADR.
</Check>
</Step>
</Steps>

## Research And Desire devices

| Device | Supported | Tested |
| --- | --- | --- |
| [Open Source Sex Machine](https://www.researchanddesire.com/open-source-sex-machine) | Yes | Yes |
| [Chastity Lockbox](https://www.researchanddesire.com/products/lockbox) | Pending | - |
| Deepthroat Trainer | Pending | - |

<Note>
Deepthroat Trainer integrations focus on cross‑device experiences and are rolling out in phases. Watch the <a href="/dtt/quick-start">Quick Start</a> and <a href="/dtt/faqs">FAQs</a> for updates.
</Note>

## Third‑party devices

| Device | Supported | Tested |
| --- | --- | --- |
| DG Labs Coyote E‑Stim Powerbox 3.0 | Pending | - |

## Buttplug.io devices

Through our partnership with Buttplug.io, RADR supports Bluetooth devices that speak the Buttplug protocol. Check their public compatibility list for the most current coverage. Feature availability varies by model; in many cases RADR provides vibration control only.

### Lovense (tested)

| Device | Supported | Tested |
| --- | --- | --- |
| Lovense Domi | Vibration Only | Yes |
| Lovense Hyphy | Vibration Only | Yes |
| Lovense Ferri | Vibration Only | Yes |

<Info>
Lovense Domi (and Domi 2) has direct integration—not via Buttplug.io—that includes battery level reading and power control commands. Other Lovense devices use the generic Buttplug.io implementation with vibration-only control.
</Info>

### Lovense (untested)

| Device | Supported | Tested |
| --- | --- | --- |
| Lovense Max | Vibration Only | - |
| Lovense Edge | Vibration Only | - |
| Lovense Nora | Vibration Only | - |
| Lovense Ambi | Vibration Only | - |
| Lovense Lush | Vibration Only | - |
| Lovense Hush | Vibration Only | - |
| Lovense Osci | Vibration Only | - |
| Lovense Mission | Vibration Only | - |
| Lovense Mission 2 | Vibration Only | - |
| Lovense Diamo | Vibration Only | - |
| Loveai Dolp | Vibration Only | - |
| Lovense Dolce | Vibration Only | - |
| Lovense Osci 3 | Vibration Only | - |
| Lovense Gush | Vibration Only | - |
| Lovense Gush 2 | Vibration Only | - |
| Lovense Calor | Vibration Only | - |
| Lovense Flexer | Vibration Only | - |
| Lovense Gemini | Vibration Only | - |
| Lovense Gravity | Vibration Only | - |
| Lovense Tenera | Vibration Only | - |
| Lovense Ridge | Vibration Only | - |
| Lovense Lapis | Vibration Only | - |
| Lovense Vulse | Vibration Only | - |
| Lovense Solace | Oscillation Only | - |
| Lovense Solace Pro | Oscillation Only | - |

### Other brands (pending support)

<AccordionGroup>
<Accordion title="We‑Vibe">
- We‑Vibe Melt
- We‑Vibe Moxie
- We‑Vibe Vector
- We‑Vibe Wand / Wand 2
- We‑Vibe Bond
- We‑Vibe Nova / Nova 2
- We‑Vibe Jive / Jive 2
- We‑Vibe Sync / Sync 2 / Sync Lite
- We‑Vibe Bloom
- We‑Vibe Ditto
- We‑Vibe Pivot
- We‑Vibe Rave
- We‑Vibe Verge
- We‑Vibe Wish
- We‑Vibe 4 Plus
- We‑Vibe Gala
</Accordion>

<Accordion title="Satisfyer">
- Satisfyer Hot Spot
- Satisfyer Love Triangle
- Satisfyer Curvy 1+ / 2+ / 3+
- Satisfyer Double Joy / Double Fun / Double Love
- Satisfyer Mono Flex / Double Flex
- Satisfyer Pro 2 Gen 3
- And many more models...
</Accordion>

<Accordion title="Kiiroo / OhMiBod">
- Kiiroo Pearl / Pearl 2 / Pearl 3
- Kiiroo Onyx / Onyx 2 / Onyx+
- Kiiroo Titan
- Kiiroo Keon
- OhMiBod Fuse
- OhMiBod Esca 2
- OhMiBod Lumen
</Accordion>

<Accordion title="LELO">
- Lelo F1s V2 / V3
- Lelo Ida Wave
- Lelo Tor 3
- Lelo Hugo 2
- Lelo Enigma Double Sonic
</Accordion>

<Accordion title="MagicMotion">
- MagicMotion Smart Bean
- MagicMotion Vini
- MagicMotion Flamingo
- MagicMotion Equinox
- MagicMotion Zenith
</Accordion>
</AccordionGroup>

<Note>
{/* TODO: Internal table required for support list. */}
For the complete list of pending devices, see the full [device support documentation](https://buttplug.io).
</Note>

## Troubleshooting

<AccordionGroup>
<Accordion title="My device doesn't appear in the scan list">
- Ensure it's a supported model and is powered on/in pairing mode
- Move the device within 1–2 meters of RADR
- Power‑cycle both RADR and the device, then rescan
- Update firmware where applicable: <a href="/ossm/guides/getting-started/web-flasher">Flashing your OSSM</a>
</Accordion>

<Accordion title="Device connects but controls don't work">
- Many third‑party devices are "Vibration Only" on first release
- Try basic intensity up/down; advanced features may be pending
- Disconnect other apps that might have claimed the device over Bluetooth
</Accordion>

<Accordion title="I need a device added or prioritized">
Open a request with brand, exact model, and a short description of what you want to control. Include any available links to the product page and Bluetooth details. Contact support@researchanddesire.com or use the website form.
</Accordion>
</AccordionGroup>

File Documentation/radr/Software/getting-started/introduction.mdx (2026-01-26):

---
title: "Software Overview"
description: "Firmware architecture and development guide for the RADR wireless remote"
sidebarTitle: "Introduction"
---

This section covers the RADR firmware, including architecture, development setup, and how to modify or contribute to the codebase.

## Firmware Overview

RADR runs on an ESP32-S3 microcontroller with custom firmware written in C++ using the Arduino framework and PlatformIO.

| Component | Technology |
|---|---|
| MCU | ESP32-S3 with PSRAM |
| Framework | Arduino for ESP32 |
| Build System | PlatformIO |
| Language | C++ |
| Display Library | TFT_eSPI |
| BLE Stack | NimBLE |

## Firmware Version

| Component | Version |
|---|---|
| Major Version | 1 |
| Minor Version | 0 |
| Patch Version | 24 |
| Full Version | 1.0.24 |

<Info>
Check for firmware updates regularly to access new features and device support.
</Info>

## Source Code

The complete firmware source is available on GitHub:

<Card title="RADR Firmware" icon="code" href="https://github.com/researchanddesire/radr-wireless-remote/tree/main/Software">
Browse the source code and documentation.
</Card>

## Architecture Overview

### Main Components

| Component | Purpose |
|---|---|
| State Machine | Manages screen states and navigation flow |
| Device Manager | Handles Bluetooth device discovery and connection |
| Display Driver | Renders UI using TFT_eSPI with canvas buffering |
| Input Handler | Processes encoder, button, and bumper inputs |
| Feedback System | Controls LEDs, buzzer, and vibration |
| Device Registry | Maps Bluetooth UUIDs to device types |

### Key Services

```
├── BluetoothService    # BLE scanning and connection
├── DisplayService      # Screen rendering
├── InputService        # Encoder and button handling
├── FeedbackService     # LED, buzzer, vibration
├── DeviceService       # Connected device control
├── WiFiService         # WiFi and OTA updates
└── StorageService      # LittleFS configuration
```

## Development Environment

### Prerequisites

- [Visual Studio Code](https://code.visualstudio.com/)
- [PlatformIO Extension](https://platformio.org/install/ide?install=vscode)
- USB-C cable for flashing

### Getting Started

<Steps>
<Step title="Clone the repository">
```bash
git clone https://github.com/researchanddesire/radr-wireless-remote.git
cd radr-wireless-remote/Software
```
</Step>

<Step title="Open in VS Code">
Open the `Software` folder in VS Code. PlatformIO will automatically detect the project configuration.
</Step>

<Step title="Build the firmware">
Click the PlatformIO Build button or run:
```bash
pio run
```
</Step>

<Step title="Flash to device">
Connect RADR via USB-C and click Upload, or run:
```bash
pio run --target upload
```
</Step>
</Steps>

## Key Features

### Canvas-Based Rendering

RADR uses double-buffered canvas rendering for smooth display updates:

- Full-screen sprites prevent flickering
- Partial updates for performance-critical areas
- Consistent 60fps UI refresh rate

### State Machine Architecture

The UI uses a hierarchical state machine:

- Clear transitions between screens
- Isolated state logic for each screen
- Event-driven input handling

### Device Registry

RADR supports multiple device types through a two-tier registry:

| Registry | Description |
|---|---|
| Built-in | Hardcoded R+D device support (OSSM) |
| Dynamic | JSON-based Buttplug.io device definitions |

The dynamic registry (`registry.json`) can be updated via firmware updates to add new device support without code changes.

## Configuration Files

| File | Purpose |
|---|---|
| `platformio.ini` | Build configuration and dependencies |
| `src/config.h` | Hardware pin definitions and constants |
| `data/registry.json` | Buttplug.io device UUID mappings |

## Technical Reference

<CardGroup cols={2}>
<Card title="Web Flasher" icon="bolt" href="/radr/tools/web-flasher">
Flash firmware using the web-based tool.
</Card>

<Card title="BLE Communication" icon="bluetooth" href="/radr/Software/communication/ble">
Bluetooth protocol details and device communication.
</Card>
</CardGroup>

## Contributing

We welcome contributions to the RADR firmware. Before contributing:

1. Read the [contribution guidelines](https://github.com/researchanddesire/radr-wireless-remote/blob/main/CONTRIBUTING.md)
2. Join the Kinky Makers Discord to discuss changes
3. Submit pull requests against the `main` branch

<DiscordInvite community="kinky-makers" />

### Code Style

- Follow existing code formatting
- Use descriptive variable and function names
- Document public functions and complex logic
- Test changes on actual hardware before submitting

## License

RADR firmware is released under the **CERN Open Hardware Licence Version 2 - Strongly Reciprocal (CERN-OHL-S v2)**. See the [licence documentation](/radr/guides/housekeeping/open-source/licence) for details.

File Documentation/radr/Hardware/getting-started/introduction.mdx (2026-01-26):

---
title: "Hardware Overview"
description: "Technical specifications and hardware documentation for the RADR wireless remote"
sidebarTitle: "Introduction"
---

This section provides technical specifications and hardware reference material for building, modifying, or understanding the RADR wireless remote.

## Device Overview

| Specification | Value |
|---|---|
| MCU | ESP32-S3 with PSRAM |
| Firmware Version | 1.0.24 |
| Display | 320 x 240 pixels, full-color TFT LCD |
| Connectivity | Bluetooth Low Energy (BLE) |
| BLE Device Name | OSSM-REMOTE |
| Transmit Power | 9 dBm |
| Charging | USB-C |
| Battery Gauge | MAX17048 (fuel gauge IC) |

## Physical Specifications

| Parameter | Value |
|---|---|
| Dimensions | Approximately 85 x 55 x 30 mm |
| Weight | ~80g (with battery) |
| Battery | Lithium Polymer (LiPo) |
| Runtime | 4+ hours typical use |

## Technical Reference

<CardGroup cols={2}>
<Card title="Feedback and Indicators" icon="lightbulb" href="/radr/Hardware/specifications/feedback-and-indicators">
LED colors, buzzer patterns, and vibration feedback details.
</Card>

<Card title="Battery and Power" icon="battery-full" href="/radr/Hardware/specifications/battery-and-power">
Battery monitoring, charging, and power management.
</Card>
</CardGroup>

## Hardware Components

### Main PCB

The RADR main board features:

- **ESP32-S3** microcontroller with WiFi and Bluetooth
- **320x240 TFT LCD** display with backlight control
- **3x WS2812B RGB LEDs** for status indication
- **Piezoelectric buzzer** for audio feedback
- **Vibration motor** for haptic feedback
- **MAX17048** fuel gauge for accurate battery monitoring
- **USB-C** for charging and initial programming
- **QWIIC connector** for expansion

### Controls

| Control | Type | GPIO Pins |
|---|---|---|
| Left Encoder | Rotary encoder with push | GPIO 10, 11 |
| Right Encoder | Rotary encoder with push | GPIO 42, 41 |
| Left Shoulder Button | Momentary | GPIO 48 |
| Right Shoulder Button | Momentary | GPIO 1 |
| Under-Screen Left | Momentary | GPIO 38 |
| Under-Screen Center | Momentary | GPIO 39 |
| Under-Screen Right | Momentary | GPIO 40 |

<Note>
Pin assignments shown are for RADR v2.x boards (with PSRAM). Earlier v1.x boards use different GPIO pins for the left encoder (GPIO 35, 36) and LEDs (GPIO 37). The firmware automatically detects and uses the correct pins for your board.
</Note>

### Display

| Parameter | Value |
|---|---|
| Resolution | 320 x 240 pixels |
| Type | TFT LCD |
| Status Bar Height | 30 pixels |
| Color Depth | 16-bit (RGB565) |

### LEDs

| Parameter | Value |
|---|---|
| LED Type | WS2812B RGB |
| LED Count | 3 |
| Control Pin | GPIO 12 |
| Positions | Left encoder, Middle, Right encoder |

### Audio/Haptic

| Component | Pin |
|---|-----|
| Buzzer | GPIO 2 |
| Vibration Motor | GPIO 47 |

## Source Files

All hardware design files are available on GitHub:

<CardGroup cols={2}>
<Card title="PCB Design Files" icon="microchip" href="https://github.com/researchanddesire/radr-wireless-remote/tree/main/Hardware/Electronics">
Altium Designer project files, schematics, and Gerber files.
</Card>

<Card title="3D Print Files" icon="cube" href="https://github.com/researchanddesire/radr-wireless-remote/tree/main/Hardware/Print%20Files">
STEP and STL files for the enclosure and buttons.
</Card>

<Card title="Bill of Materials" icon="list" href="https://github.com/researchanddesire/radr-wireless-remote/tree/main/Hardware">
Complete parts list with supplier links.
</Card>

<Card title="Assembly Guide" icon="screwdriver-wrench" href="https://github.com/researchanddesire/radr-wireless-remote">
Step-by-step build instructions (see GitHub).
</Card>
</CardGroup>

## Bluetooth Specifications

### Scan Parameters

| Parameter | Value |
|---|---|
| Scan Interval | 100ms |
| Scan Window | 100ms |
| Scan Type | Active |
| Scan Duration | 5000ms (5 seconds) |

### Connection Parameters

| Parameter | Value |
|---|---|
| Min Interval | 12 (15ms) |
| Max Interval | 12 (15ms) |
| Latency | 0 |
| Supervision Timeout | 150 (1500ms) |
| Connect Timeout | 5000ms |

## Supported Device UUIDs

### Research And Desire

| Device | Service UUID |
|---|---|
| OSSM | 522B443A-4F53-534D-0001-420BADBABE69 |
| LKBX | Pending |
| DTT | Pending |

### Lovense

| Device | Service UUID |
|---|---|
| Domi 2 | 57300001-0023-4BD4-BBD5-A6920E4C5653 |
| Other Lovense | Various (via Buttplug.io registry) |

## Control Ranges

### OSSM Parameters

| Parameter | Min | Max | Default |
|---|-----|-----|---|
| Speed | 0% | 100% | 0% |
| Depth | 0% | 100% | 10% |
| Sensation | 0% | 100% | 50% |
| Stroke | 0% | 100% | 50% |

### Lovense Parameters

| Parameter | Min | Max | Default |
|---|-----|-----|---|
| Vibrate | 0 | 16 | 0 |

## Building Your Own RADR

If you want to build your own RADR, you'll need:

### Electronics

- RADR PCB (order from JLCPCB, PCBWay, or similar)
- Components from the Bill of Materials
- USB-C cable for programming
- LiPo battery (check BoM for specifications)

### Printed Parts

- Top housing
- Bottom housing
- Buttons (3x)
- Encoder knobs (2x)
- Power switch cap

### Tools Required

- Soldering iron with fine tip
- Hot air rework station (recommended)
- 3D printer (or order prints)
- Small screwdrivers

<Card title="Print Guidance" icon="print" href="/radr/Hardware/printed-parts/introduction">
Recommended print settings and multi-color options.
</Card>

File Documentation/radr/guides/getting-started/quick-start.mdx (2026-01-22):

---
title: "Quick Start"
description: "Get your Research And Desire Wireless Remote (RADR) set up and connected to your OSSM or Bluetooth device in minutes."
sidebarTitle: "Quick Start"
---

<iframe
  className="w-full aspect-video rounded-xl"
  src="https://www.youtube.com/embed/SqUHOGLTgAE"
  title="RADR Quick Start Video"
  frameBorder="0"
  allow="accelerometer; autoplay; clipboard-write; encrypted-media; gyroscope; picture-in-picture"
  allowFullScreen
></iframe>

<Accordion title="Video transcript">
Today I have the new Research and Desire wireless remote, also called the RADR. And I'm super excited to show you how it connects with both OSSM and also a wireless Bluetooth device like the Domi right here. In order to control the OSSM, you have to make sure that you have updated your firmware to the newest version. Once you've done that, just make sure that your machine is plugged in and turned on. And I'll show you how it connects really quickly. I'm turning on the power switch. And as you can see, it is automatically searching for the device and voila, it is connected. You don't have to do anything else.

I'll go over some of the specifics of the remote now. The left-hand knob always controls speed and the right-hand knob toggles and adjusts depth, sensation, and stroke. I'm going to turn up the speed a little bit here so you can see that's going. Right now I'm in Stroke; as I move the Stroke knob, you can see one of the rings go up and down, so you can always see where you're at in terms of how much stroke you have on.

The buttons: this button here is Pattern. If you click into it, you'll be able to take a look at all the different patterns and you can select one using the Pattern button again. This button here is stop and go—pause or play. There we go, it stopped the OSSM immediately; click it again and the device is stopped. Once it stops you can just turn up the speed again and it'll start working again. And that's it for controlling the OSSM.

I also want to show you how to control the Domi. I'm going to turn off the OSSM and unplug it. Now I've got my Domi; I'll turn it on and do the same thing as with the OSSM. I turn on the RADR and it automatically searches for the device. And look at that—it connects to my Domi. I can play with the knob, and there's that stop button as well. There you have it: the wireless RADR connecting to both the Domi and the OSSM.
</Accordion>

RADR started as a wireless, user‑friendly controller for the OSSM (Open‑Source Sex Machine), created in partnership with The Kinkymakers. It has since evolved into a versatile wireless controller for a range of Bluetooth‑enabled devices using the Buttplug.io protocol.

This guide helps you pair your RADR with the OSSM and get playing in minutes. The same process applies to other supported devices like the Lovense Domi 2.

<Card title="Device support" icon="bluetooth" href="../reference/device-support">
View the complete list of supported Bluetooth devices.
</Card>

## Getting started

### Prerequisites

- RADR charged (USB‑C)
- Supported device powered on nearby (OSSM, Lovense Domi 2, etc.)
- OSSM firmware version 2.0.0 or later
- No other apps or controllers currently connected to the Bluetooth device

<Note>
RADR only connects to supported devices. See <a href="../reference/device-support">Device support</a> for details.
</Note>

### Remote layout

<Frame>
RADR remote layout: screen, three buttons, left/right knobs, and bumpers
</Frame>

The RADR provides tactile, glanceable controls you can operate without looking away.

- Top edge
  - Left bumper — mode previous
  - Power switch — above the screen, to the left of the USB‑C port
  - Right bumper — mode next
- Front face
  - Full‑color LCD centered on the device
  - Three buttons below the screen
    - Left button — Home / Back
    - Middle button — Pause / Stop
    - Right button — Menu / OK
- Sides
  - Left knob (encoder) — Speed
  - Right knob (encoder) — Depth, Sensation, or Stroke (based on the current mode)

### Powering on

<Steps>
<Step title="Charge your RADR">
Connect RADR to a power source with a USB‑C cable and allow it to charge.

<Check>
RADR turns on and the battery icon appears on screen.
</Check>
</Step>

<Step title="Turn on RADR">
Flip the power switch to the right (toward the USB‑C port).

<Info>
RADR automatically scans for nearby supported Bluetooth devices.
</Info>
</Step>

<Step title="Prepare your device">
- For OSSM: Power it on and let it finish homing.
- For other devices (e.g., Lovense Domi 2): Power on and ensure no phone app is connected.

<Warning>
Only one controller/app can be connected to a Bluetooth device at a time. Close vendor apps (e.g., Lovense) before pairing with RADR.
</Warning>
</Step>
</Steps>

<Card title="Device support" icon="list-check" href="../reference/device-support">
Check which devices are compatible with RADR.
</Card>

### Pairing with the OSSM

<Steps>
<Step title="Update your OSSM firmware">
Ensure your OSSM is running firmware 2.0.0 or higher.

<Card title="Flashing your OSSM" icon="microchip" href="/ossm/guides/getting-started/web-flasher">
Follow our firmware update guide if you need to update your OSSM.
</Card>
</Step>

<Step title="Power on and home the OSSM">
Turn on your OSSM and allow it to complete its homing routine. Keep it powered on.
</Step>

<Step title="Scan for devices">
RADR automatically scans for nearby Bluetooth devices for 5 seconds when powered on. A blue LED pulses during the search.

<Info>
You can also start a manual scan from the main menu by selecting **Device Search**.
</Info>
</Step>

<Step title="Select your device">
After scanning, RADR displays a list of discovered devices. Use the right knob to scroll through the list, then press the right button to connect to your OSSM.

<Check>
Connection status messages appear: "Connecting...", "Connected! Setting up device...", and finally "Device ready!"
</Check>
</Step>

<Step title="Start playing">
The Play Controls screen appears once connected. The middle LED turns white to indicate an active connection.

<Check>
You can now control your OSSM using the knobs, bumpers, and buttons.
</Check>
</Step>
</Steps>

## Play controls

When RADR is paired, you'll see the Play Controls screen.

<Frame>
Play Controls screen with speed and adjustment indicators
</Frame>

| Control | Action |
|---|---|
| Left knob | Adjust speed (0–100%) |
| Right knob | Adjust the active mode (Depth, Sensation, or Stroke) |
| Left/Right bumper | Cycle through adjustment modes |
| Left button | Reserved for future device settings (currently disabled) |
| Middle button | **Single press:** Pause — sets speed to 0, displays red "Paused" text, middle LED turns red. **Double press:** Full Stop — resets Depth to 0%, Stroke to 10%, Sensation to 50% |
| Right button | Open Pattern Mode |

<Tip>
Use the bumpers to switch modes without looking down. The on‑screen tabs show which mode is active: Depth, Sensation, or Stroke.
</Tip>

<Info>
When paused, increase the speed with the left knob to resume playback automatically. The middle LED returns to white when active.
</Info>

## Pattern mode

<Frame>
Pattern Mode screen with a library of motion patterns
</Frame>

Press the right button to enter Pattern Mode and choose from built‑in motion patterns.

| Control | Action |
|---|---|
| Left knob | Adjust speed |
| Right knob | Scroll through patterns |
| Left/Right bumper | No action |
| Left button | Exit to Play Controls without applying |
| Middle button | Pause and exit to Play Controls |
| Right button | Select the highlighted pattern |

<Tip>
New patterns are added over time. Check for firmware updates to access the latest libraries.
</Tip>

## Sleep mode

To conserve battery when not in use, RADR offers a deep sleep mode accessible from the main menu.

<Steps>
<Step title="Access the main menu">
From the Play Controls screen, press the left button to return to the main menu (when paused) or disconnect your device first.
</Step>

<Step title="Select Sleep">
Navigate to **Sleep** using the right knob and press the right button. RADR plays a shutdown sound, turns off the display, and enters deep sleep.
</Step>

<Step title="Wake up">
Press any of the three under-screen buttons to wake RADR. The device restarts and returns to the main menu.
</Step>
</Steps>

## Connection recovery

If RADR loses connection—due to distance, power loss, or Bluetooth interference—it automatically attempts to reconnect within 2–5 seconds.

<Warning>
If reconnection doesn't happen quickly, OSSM gradually ramps down and pauses for safety.
</Warning>

If reconnection fails, power‑cycle both the RADR and your device. They will pair automatically on restart.

## Power saving

To extend battery life, RADR automatically dims the screen after 30 seconds of inactivity. After 2 minutes without interaction, the screen enters a deeper power-saving mode, and after 10 minutes of inactivity, the screen turns off completely.

Any button press or encoder rotation will instantly restore the screen to full brightness.

## Troubleshooting

<AccordionGroup>
<Accordion title="RADR doesn't find my device">
- Ensure the device is powered on and charged
- Move within 1–2 meters for initial pairing
- Close vendor phone apps (Lovense, etc.) so RADR can take the connection
- Power‑cycle RADR and the device, then retry
- For OSSM, confirm firmware ≥ 2.0.0
</Accordion>

<Accordion title="OSSM isn't moving after I press Pause/Stop">
- Increase speed with the left knob to resume from Pause
- If you double‑pressed Stop, defaults are restored—re‑set your mode and adjustments
- Verify the OSSM completed homing and is not physically obstructed
</Accordion>

<Accordion title="Patterns don't start">
- Ensure speed is set above 0
- Select a pattern with the right button (Menu/OK)
- Exit Pattern Mode (left button) and re‑enter if the screen appears unresponsive
</Accordion>

<Accordion title="Frequent disconnects">
- Reduce interference: move away from Wi‑Fi routers and metal surfaces
- Keep phone apps closed to prevent connection stealing
- Update firmware on both RADR and your device when updates are available
</Accordion>

<Accordion title="Encoder knobs are unresponsive or make erratic jumps">
If the left (speed) or right (depth/sensation/stroke) encoder knob doesn't respond, responds intermittently, or makes large unpredictable jumps in value:

1. **Update firmware** — Flash the latest firmware to both RADR and your device using the <a href="/radr/tools/web-flasher">Web Flasher</a>
2. **Power-cycle** — Turn RADR off and on again
3. **Test both knobs** — Determine if the issue affects one knob, both knobs, or alternates between them

If the problem persists after updating firmware, this indicates a hardware defect with the encoder component. Contact support for a replacement.

<Card title="Contact Support" icon="headset" href="mailto:support@researchanddesire.com">
Get help from our support team.
</Card>
</Accordion>
</AccordionGroup>

## Next steps

Once you've completed setup, you should have:

- A charged RADR paired to your device
- OSSM or another supported device on current firmware
- Wireless control without cables or legacy displays

<CardGroup cols={2}>
<Card title="OSSM Controls" icon="sliders" href="../user-guide/ossm-controls">
Learn about speed, depth, sensation, and stroke modes.
</Card>

<Card title="Stroke Patterns" icon="wave-pulse" href="../user-guide/stroke-patterns">
Explore the 7 built-in motion patterns.
</Card>

<Card title="Navigation Guide" icon="gamepad" href="../user-guide/navigation-and-controls">
Complete guide to buttons, menus, and screen navigation.
</Card>

<Card title="Device Support" icon="bluetooth" href="../reference/device-support">
View all compatible Bluetooth devices.
</Card>

<Card title="Settings and WiFi" icon="wifi" href="../user-guide/settings-and-wifi">
Configure WiFi and access device settings.
</Card>

<Card title="Firmware Updates" icon="download" href="/ossm/guides/getting-started/web-flasher">
Keep your devices up to date.
</Card>
</CardGroup>

Enjoy your Research And Desire Wireless Remote—designed for seamless, intuitive control across the RAD ecosystem.

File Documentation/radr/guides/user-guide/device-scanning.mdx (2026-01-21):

---
title: "Device Scanning"
description: "How RADR discovers and connects to Bluetooth devices"
sidebarTitle: "Device Scanning"
---

This guide explains how RADR discovers nearby Bluetooth devices and establishes connections.

## Automatic Scanning

When you power on RADR, it automatically scans for nearby supported Bluetooth devices.

### Scan Behavior

- **Duration:** 5 seconds
- **LED Indicator:** Blue pulsing during scan
- **Status Message:** "Searching for nearby devices..."

During the scan:
1. RADR broadcasts as "OSSM-REMOTE" with high transmit power (9 dBm)
2. It searches for devices advertising supported service UUIDs
3. Discovered devices are added to the device list

## Manual Scanning

To start a manual scan:

1. From the main menu, select **Device Search**
2. RADR scans for 5 seconds
3. After scanning, the device list appears

<Tip>
Use manual scanning when you've powered on a new device after RADR's initial boot scan.
</Tip>

## Device List

After scanning, the device list shows all discovered devices:

- Devices are shown by their advertised Bluetooth name
- If a device has no name, it appears as "Unknown Device"
- The list is scrollable if multiple devices are found

### Navigating the Device List

| Control | Action |
|---|---|
| Right Encoder | Scroll through devices |
| Right Button | Connect to selected device |
| Left Button | Cancel and return to main menu |

## Connecting to a Device

When you select a device from the list, RADR initiates a connection:

### Connection Status Messages

You'll see these status messages in sequence:

1. **"Initializing connection..."** — Setting up the connection process
2. **"Checking existing connections..."** — Verifying no conflicts
3. **"Attempting fast reconnect..."** — Trying quick reconnection if previously paired
4. **"Creating new connection..."** — Establishing a new Bluetooth connection
5. **"Connecting to [address]..."** — Connecting to the specific device
6. **"Connected! Setting up device..."** — Connection established, configuring
7. **"Discovering device capabilities..."** — Reading device features
8. **"Device ready!"** — Connection complete, entering control mode

### Connection Parameters

RADR uses optimized connection parameters for responsive control:

| Parameter | Value |
|---|---|
| Connection interval | 15ms |
| Latency | 0 |
| Timeout | 1500ms |
| Connect timeout | 5000ms |

## Connection Failures

If connection fails, you'll see:

- **"Connection failed, please try again."** — General connection failure
- **"Connection limit reached!"** — Too many active BLE connections
- **"Device service not found!"** — Device doesn't have expected services

### Troubleshooting Connection Issues

<AccordionGroup>
<Accordion title="Device doesn't appear in scan">
- Ensure the device is powered on and in pairing mode
- Move within 1–2 meters for initial pairing
- Close any phone apps that might be connected to the device
- Power-cycle both RADR and the target device
</Accordion>

<Accordion title="Connection fails repeatedly">
- Ensure no other app or controller is connected
- Power-cycle the target device
- Move closer to reduce interference
- For OSSM: Ensure firmware is 2.0.0 or higher
</Accordion>

<Accordion title="Connection drops frequently">
- Stay within Bluetooth range (typically 10 meters indoors)
- Reduce interference from WiFi routers and other Bluetooth devices
- Keep phone apps closed to prevent connection stealing
</Accordion>
</AccordionGroup>

## One Device at a Time

<Warning>
RADR can only connect to **one device at a time**. To switch to a different device, you must first disconnect from the current device.
</Warning>

To disconnect and switch devices:

1. From the control screen, press left button to access the menu (when paused)
2. Navigate back to the main menu
3. Start a new device search

## Device Registry

RADR uses a two-tier device registry to identify supported devices:

### Built-in Registry

- Hardcoded support for Research And Desire devices (OSSM)
- Always available and cannot be modified
- Provides full-featured control interfaces

### Dynamic Registry (registry.json)

- Stored in RADR's internal filesystem (LittleFS)
- Contains Buttplug.io device UUIDs and configurations
- **Can be updated via firmware updates without changing the core application**
- This allows faster device support additions

When scanning, RADR checks both registries to identify devices by their Bluetooth service UUIDs.

<Info>
The dynamic registry enables Research And Desire to add support for new devices more frequently, as it only requires updating a configuration file rather than the entire firmware.
</Info>

### Supported Device Types

| Device Type | Control Interface |
|---|---|
| OSSM | Full control (Speed, Depth, Sensation, Stroke, Patterns) |
| Lovense | Vibration-only control (0–16 levels) |
| Buttplug.io devices | Varies by device capabilities |

## Reconnection Behavior

If RADR loses connection to a device:

1. RADR automatically attempts to reconnect within 2–5 seconds
2. For OSSM: The machine gradually ramps down for safety
3. If reconnection fails, return to the main menu and rescan

<Info>
RADR remembers recently connected devices and attempts fast reconnection when possible.
</Info>

## Tips

<Tip>
For reliable connections, ensure only RADR is attempting to connect to your device. Close phone apps and other controllers.
</Tip>

<Tip>
If a device appears as "Unknown Device," it's still safe to connect—the control interface will be determined by the device's capabilities.
</Tip>

<Tip>
Keep RADR firmware updated to ensure compatibility with the latest devices.
</Tip>

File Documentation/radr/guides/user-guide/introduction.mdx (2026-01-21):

---
title: "User Guides"
description: "Comprehensive guides for using your Research And Desire Wireless Remote (RADR)"
sidebarTitle: "Introduction"
---

Welcome to the RADR user guides. These guides cover everything you need to know to get the most out of your wireless remote controller.

<Info>
These guides cover RADR firmware version **1.0.24**. Some features may differ in earlier or later versions.
</Info>

## Getting Started

If you're new to RADR, start with these essential guides:

<CardGroup cols={2}>
<Card title="Quick Start" icon="rocket" href="../getting-started/quick-start">
Get your RADR set up and paired in minutes.
</Card>

<Card title="Navigation and Controls" icon="gamepad" href="./navigation-and-controls">
Learn how to navigate menus and use all the buttons.
</Card>
</CardGroup>

## Device Control Guides

RADR supports multiple device types, each with their own control interface:

<CardGroup cols={2}>
<Card title="OSSM Controls" icon="sliders" href="./ossm-controls">
Control the Open Source Sex Machine with speed, depth, sensation, and stroke modes.
</Card>

<Card title="Stroke Patterns" icon="wave-pulse" href="./stroke-patterns">
Explore the 7 built-in motion patterns for OSSM.
</Card>

<Card title="Lovense Controls" icon="circle-dot" href="./lovense-controls">
Control Lovense devices with the simplified vibration interface.
</Card>

<Card title="Device Support" icon="bluetooth" href="../reference/device-support">
View all compatible Bluetooth devices.
</Card>
</CardGroup>

## Settings and Configuration

<CardGroup cols={2}>
<Card title="Device Scanning" icon="radar" href="./device-scanning">
How RADR discovers and connects to Bluetooth devices.
</Card>

<Card title="Settings and WiFi" icon="wifi" href="./settings-and-wifi">
Configure WiFi for updates and access device settings.
</Card>
</CardGroup>

## Technical Reference

For detailed technical information about RADR hardware:

<CardGroup cols={2}>
<Card title="Feedback and Indicators" icon="lightbulb" href="/radr/Hardware/specifications/feedback-and-indicators">
LED colors, buzzer sounds, and vibration patterns explained.
</Card>

<Card title="Battery and Power" icon="battery-full" href="/radr/Hardware/specifications/battery-and-power">
Battery status, charging, and power management.
</Card>
</CardGroup>

## Quick Reference

### Physical Controls

| Control | Location | Primary Function |
|---|---|---|
| Left Encoder | Left side | Speed control |
| Right Encoder | Right side | Mode adjustment (Depth/Sensation/Stroke) |
| Left Bumper | Top left | Previous mode |
| Right Bumper | Top right | Next mode |
| Left Button | Below screen (left) | Back / Home |
| Middle Button | Below screen (center) | Pause / Stop |
| Right Button | Below screen (right) | Menu / OK / Patterns |

### LED Color Meanings

| Color | Meaning |
|---|---|
| Blue (pulsing) | Searching for devices |
| White | Connected and active |
| Red | Paused or stopped |
| Green | Device connected confirmation |

### Default OSSM Settings

When you first connect to an OSSM, these initial defaults are used:

| Parameter | Default Value |
|---|---|
| Speed | 0% |
| Depth | 10% |
| Sensation | 50% |
| Stroke | 50% |
| Pattern | Simple Stroke |

<Note>
After a **Full Stop** (double-press middle button), different reset values are applied: Depth 0%, Stroke 10%, Sensation 50%. This is intentional for safety—the device starts in a minimal movement state.
</Note>

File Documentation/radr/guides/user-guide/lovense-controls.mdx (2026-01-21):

---
title: "Lovense Controls"
description: "Guide to controlling Lovense devices with RADR"
sidebarTitle: "Lovense Controls"
---

RADR supports Lovense Bluetooth devices with a simplified vibration-only control interface. This guide covers how to control Lovense devices.

<Note>
RADR provides **vibration-only** control for Lovense devices. Advanced features like heating, rotation, or device-specific patterns are not currently supported.
</Note>

## Supported Lovense Devices

RADR has been tested with the following Lovense devices:

| Device | Status |
|---|---|
| Lovense Domi | Tested |
| Lovense Hyphy | Tested |
| Lovense Ferri | Tested |

Many other Lovense devices are supported but untested. See [Device Support](../reference/device-support) for the complete list.

## Control Screen Overview

When connected to a Lovense device, the control screen is simpler than the OSSM interface:

- **Left Encoder Dial:** Vibration intensity control
- **Center Button:** STOP button
- **Display:** Shows vibration level and device status

## Vibration Control

The **left encoder** controls vibration intensity.

| Parameter | Range | Default |
|---|---|---|
| Vibrate | 0–16 | 0 |

- Turn clockwise to increase intensity
- Turn counter-clockwise to decrease intensity
- Setting to 0 stops vibration

<Info>
Lovense devices use a 0–16 intensity scale, not percentage. Level 16 is maximum intensity.
</Info>

## Stop Button

The **middle button** acts as an immediate stop:

- Press to set vibration to 0
- The device stops vibrating immediately

Unlike the OSSM, there's no pause/resume state—simply increase the vibration level to restart.

<Info>
For reliability, RADR sends the stop command twice with a brief delay. This ensures the command is received even if the first transmission is lost due to Bluetooth interference.
</Info>

## Battery Level

For Lovense Domi (and Domi 2), RADR can query the device's battery level via its direct integration:

- Battery percentage is shown on screen
- Check battery status before sessions to avoid interruptions

<Note>
Battery level is available for Domi devices via direct Bluetooth integration. Other Lovense devices may or may not support battery level reporting depending on their Buttplug.io implementation.
</Note>

## Connecting to Lovense Devices

<Steps>
<Step title="Prepare your Lovense device">
Turn on your Lovense device. Ensure the Lovense app is **closed** on your phone—only one controller can connect at a time.
</Step>

<Step title="Scan with RADR">
Turn on RADR or select **Device Search** from the main menu. RADR scans for 5 seconds.
</Step>

<Step title="Select your device">
Your Lovense device appears in the device list. Select it with the right button to connect.
</Step>

<Step title="Start controlling">
Once connected, use the left encoder to control vibration intensity.
</Step>
</Steps>

<Warning>
Close the Lovense phone app before connecting with RADR. Bluetooth devices can only have one active controller.
</Warning>

## Limitations vs Native App

RADR provides basic vibration control. The following features are **not** available:

| Feature | RADR | Lovense App |
|---|---|---|
| Basic vibration | Yes | Yes |
| Vibration patterns | No | Yes |
| Remote partner control | No | Yes |
| Sound-reactive modes | No | Yes |
| Alarm features | No | Yes |
| Device settings | No | Yes |
| Firmware updates | No | Yes |

<Tip>
Use RADR when you want tactile, physical controls without a phone. Use the Lovense app for advanced features and remote play.
</Tip>

## Quick Reference

| Control | Action |
|---|---|
| Left Encoder | Adjust vibration (0–16) |
| Right Encoder | Not used |
| Left Bumper | Not used |
| Right Bumper | Not used |
| Left Button | Back to main menu |
| Middle Button | Stop (set to 0) |
| Right Button | Not used |

## Troubleshooting

<AccordionGroup>
<Accordion title="Lovense device doesn't appear in scan">
- Ensure the device is powered on (LED blinking)
- Close the Lovense phone app completely
- Move RADR within 1–2 meters of the device
- Power-cycle both devices and retry
</Accordion>

<Accordion title="Device connects but doesn't vibrate">
- Ensure vibration level is above 0
- Check that the device has battery charge
- Some devices need a few seconds after connection to initialize
</Accordion>

<Accordion title="Vibration is inconsistent">
- Reduce distance between RADR and the device
- Move away from WiFi routers and other Bluetooth devices
- Ensure no other apps are trying to connect
</Accordion>
</AccordionGroup>

## Tips

<Tip>
Start at a low intensity level (2–4) and gradually increase to find your preferred setting.
</Tip>

<Tip>
The encoder provides quick access to all 17 levels (0–16). You can rapidly scroll through intensities.
</Tip>

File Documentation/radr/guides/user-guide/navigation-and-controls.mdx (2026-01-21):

---
title: "Navigation and Controls"
description: "Complete guide to RADR button mappings, menu navigation, and screen states"
sidebarTitle: "Navigation"
---

This guide covers how to navigate RADR's menus and screens using the physical controls.

## Physical Control Layout

RADR has the following physical controls:

### Top Edge
- **Left Bumper** — Located on the top-left edge, used for switching to the previous mode
- **Power Switch** — Above the screen, to the left of the USB-C port
- **Right Bumper** — Located on the top-right edge, used for switching to the next mode

### Front Face
- **320x240 Full-Color LCD** — Centered on the device
- **Three Under-Screen Buttons:**
  - **Left Button** — Home / Back
  - **Middle Button** — Pause / Stop (single press pauses, double press stops and resets)
  - **Right Button** — Menu / OK / Select

### Sides
- **Left Encoder (Knob)** — Always controls speed or primary parameter
- **Right Encoder (Knob)** — Controls secondary parameters or selection

## Main Menu

The main menu is your starting point after powering on RADR. It offers three options:

| Option | Icon | Description |
|---|---|---|
| Device Search | Waves | Scan for nearby Bluetooth devices |
| Settings | Gear | Access WiFi and device settings |
| Sleep | Moon | Enter deep sleep mode to conserve battery |

### Navigation
- **Right Encoder** — Scroll through menu options
- **Right Button** — Select the highlighted option
- **Left Button** — No action (already at top level)

## Settings Menu

Access the settings menu from the main menu by selecting **Settings**.

| Option | Description |
|---|---|
| Go Back | Return to the main menu |
| WiFi Settings | Configure WiFi for OTA updates |
| Update Device | Check for and install firmware updates |
| Restart Device | Reboot the RADR |

### Navigation
- **Right Encoder** — Scroll through options
- **Right Button** — Select the highlighted option
- **Left Button** — Return to main menu

## Screen States

RADR uses a state machine to manage different screens. Here's the flow:

```mermaid
flowchart TD
    Boot[Power On] --> MainMenu[Main Menu]
    MainMenu --> DeviceSearch[Device Search]
    MainMenu --> Settings[Settings Menu]
    MainMenu --> Sleep[Deep Sleep]
    
    DeviceSearch --> DeviceList[Device List]
    DeviceList --> Connecting[Connecting]
    DeviceList --> MainMenu
    
    Connecting --> Control[Device Control]
    Connecting --> DeviceList
    
    Control --> DeviceMenu[Device Menu]
    Control --> DeviceStop[Device Stopped]
    DeviceMenu --> Control
    DeviceStop --> Control
    DeviceStop --> MainMenu
    
    Settings --> WiFiSetup[WiFi Setup]
    Settings --> MainMenu
    WiFiSetup --> WiFiConnected[WiFi Connected]
    WiFiConnected --> MainMenu
    
    Sleep --> Boot
```

### Device Search Screen

When you select **Device Search** from the main menu:

1. RADR scans for 5 seconds
2. Blue LEDs pulse during the scan
3. Status shows "Searching for nearby devices..."
4. After scanning, the device list appears

### Device List Screen

After scanning, you'll see a list of discovered devices:

- **Right Encoder** — Scroll through the device list
- **Right Button** — Connect to the selected device
- **Left Button** — Cancel and return to main menu

<Info>
Devices are shown by their advertised name. If a device has no name, it appears as "Unknown Device".
</Info>

### Device Connecting Screen

During connection, you'll see status messages:

1. "Initializing connection..."
2. "Creating new connection..."
3. "Connecting to [device address]..."
4. "Connected! Setting up device..."
5. "Discovering device capabilities..."
6. "Device ready!"

<Warning>
If connection fails, you'll see "Connection failed, please try again." Power-cycle both devices and retry.
</Warning>

### Device Control Screen

Once connected, you enter the device control screen. The layout varies by device type:

**For OSSM:**
- Tab interface at top showing Depth, Sensation, Stroke modes
- Left encoder dial for Speed
- Right encoder dial for the active mode
- Bottom buttons: Menu (disabled), Pause, Patterns

**For Lovense:**
- Single encoder dial for vibration intensity
- STOP button in the center

See [OSSM Controls](./ossm-controls) or [Lovense Controls](./lovense-controls) for device-specific details.

### Device Menu Screen

For devices that support patterns (like OSSM), pressing the right button opens the pattern menu:

- **Right Encoder** — Scroll through patterns
- **Right Button** — Select the highlighted pattern
- **Left Button** — Return to control screen without changing

### Device Stopped Screen

After a double-press stop, this confirmation screen appears:

- **Message:** "Your device has been stopped and reset to default play settings; but it's still connected."
- **Left Button (Back)** — Return to control screen
- **Right Button (Home)** — Return to main menu

## Button Behavior by Screen

| Screen | Left Button | Middle Button | Right Button |
|---|---|---|---|
| Main Menu | — | — | Select option |
| Settings Menu | Back to main | — | Select option |
| Device Search | Cancel | — | — |
| Device List | Cancel | — | Connect |
| Device Control | Menu (if enabled) | Pause/Stop | Patterns/Menu |
| Device Menu | Back to control | Pause | Select pattern |
| WiFi Setup | Cancel | — | — |

## Encoder Behavior by Screen

| Screen | Left Encoder | Right Encoder |
|---|---|---|
| Main Menu | — | Scroll options |
| Settings Menu | — | Scroll options |
| Device List | — | Scroll devices |
| Device Control | Speed (0-100%) | Active mode (0-100%) |
| Device Menu | Speed (0-100%) | Scroll patterns |

## Tips for Navigation

<Tip>
You can access the main menu from most screens by pressing the left button repeatedly to go back.
</Tip>

<Tip>
The bumper buttons (top edge) switch between Depth, Sensation, and Stroke modes without looking at the screen. The active mode is shown in the tab interface.
</Tip>

<Warning>
RADR can only connect to one device at a time. To switch devices, disconnect the current device first by returning to the main menu.
</Warning>

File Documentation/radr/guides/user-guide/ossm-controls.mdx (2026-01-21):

---
title: "OSSM Controls"
description: "Complete guide to controlling the Open Source Sex Machine with RADR"
sidebarTitle: "OSSM Controls"
---

This guide covers how to control the OSSM (Open Source Sex Machine) using your RADR wireless remote.

## Control Screen Overview

When connected to an OSSM, the control screen displays:

- **Top:** Three tabs showing Depth, Sensation, and Stroke modes
- **Top Bumpers:** `<<` and `>>` buttons for mode switching
- **Left Side:** Speed encoder dial with arc indicator
- **Right Side:** Mode encoder dial (Depth/Sensation/Stroke) with arc indicator
- **Center:** Linear rail graph showing stroke and depth visualization
- **Below Graph:** Current pattern name
- **Bottom:** Menu, Pause, and Patterns buttons

## Speed Control

The **left encoder** always controls speed, regardless of which mode is active.

| Parameter | Range | Default |
|---|---|---|
| Speed | 0–100% | 0% |

- Turn clockwise to increase speed
- Turn counter-clockwise to decrease speed
- The encoder has acceleration: faster turns make bigger changes

<Info>
Speed must be above 0% for the OSSM to move. When paused, increase speed to resume automatically.
</Info>

## Adjustment Modes

The **right encoder** controls one of three parameters, depending on which mode is active. Use the shoulder bumpers to switch modes.

### Depth Mode

Controls how deep the penetration reaches.

| Parameter | Range | Default |
|---|---|---|
| Depth | 0–100% | 10% |

- Higher values = deeper penetration
- The depth is visualized on the linear rail graph

### Sensation Mode

Controls the intensity or "feel" of the motion.

| Parameter | Range | Default |
|---|---|---|
| Sensation | 0–100% | 50% |

- Lower values = gentler, smoother motion
- Higher values = more intense, aggressive motion

### Stroke Mode

Controls the length of each stroke.

| Parameter | Range | Default |
|---|---|---|
| Stroke | 0–100% | 50% |

- Lower values = shorter strokes
- Higher values = longer strokes
- The stroke is visualized on the linear rail graph

## Switching Modes

You have two ways to switch between Depth, Sensation, and Stroke:

### Using Bumpers (Recommended)
- **Left Bumper (`<<`)** — Switch to the previous mode
- **Right Bumper (`>>`)** — Switch to the next mode

The mode order is: Depth → Sensation → Stroke → Depth...

### Visual Feedback
When you switch modes:
- The corresponding tab at the top becomes highlighted
- The right encoder LED color changes:
  - **Coral/Red** — Depth mode
  - **Blue** — Sensation mode
  - **Green** — Stroke mode
- The left encoder LED stays **purple** (always speed)

## Pause and Stop

The **middle button** controls pausing and stopping.

### Single Press: Pause

A single press pauses the OSSM:
- Speed is set to 0%
- The pattern name changes to "Paused" in red
- The middle LED turns red
- The Pause button changes to "STOP" (red)

<Info>
To resume from pause, simply increase the speed with the left encoder. The OSSM will resume automatically.
</Info>

### Safety Feature: Persistent Speed Monitoring

When you enter Pattern Mode or other menus, RADR continues to monitor the left encoder (speed) for safety. This means:

- You can still adjust speed while browsing patterns
- If you turn the speed to 0, the OSSM stops immediately
- This ensures you always have instant stop capability

<Tip>
Even while selecting patterns, the left encoder controls speed. This is a safety feature, not a bug.
</Tip>

### Double Press: Full Stop

A quick double press performs a full stop with reset:
- Speed is set to 0%
- Depth is reset to 0%
- Stroke is reset to 10%
- Sensation is reset to 50%
- The "Device Stopped" confirmation screen appears

<Warning>
Full stop resets your adjustment settings. If you want to pause without losing your settings, use a single press.
</Warning>

## Pattern Mode

Press the **right button (Patterns)** to enter Pattern Mode.

In Pattern Mode:
- The screen shows a list of available patterns
- Use the right encoder to scroll through patterns
- Press the right button to select a pattern
- Press the left button to cancel and return

See [Stroke Patterns](./stroke-patterns) for details on each pattern.

## Linear Rail Graph

The linear rail graph in the center of the screen provides a visual representation of the OSSM's motion:

- The graph shows the stroke range and depth position
- As you adjust Stroke and Depth, the visualization updates in real-time
- This helps you understand the physical motion without looking at the machine

## Menu Button

The **left button (Menu)** is reserved for future OSSM device settings.

<Note>
The Menu button is currently disabled and has no function. The button styling changes when paused (appearing enabled), but pressing it has no effect. Future firmware updates will enable device-specific settings through this button.
</Note>

## LED Indicators During Control

| LED | Color | Meaning |
|-----|---|---|
| Left (Speed) | Purple | Speed mode (always active) |
| Middle | White | Active and playing |
| Middle | Red | Paused or stopped |
| Right (Mode) | Coral/Red | Depth mode active |
| Right (Mode) | Blue | Sensation mode active |
| Right (Mode) | Green | Stroke mode active |

## Quick Reference

| Control | Action |
|---|---|
| Left Encoder | Adjust speed (0–100%) |
| Right Encoder | Adjust active mode (0–100%) |
| Left Bumper | Previous mode (Depth ← Sensation ← Stroke) |
| Right Bumper | Next mode (Depth → Sensation → Stroke) |
| Left Button | Menu (disabled) |
| Middle Button | Single: Pause / Double: Full Stop |
| Right Button | Open Pattern Mode |

## Tips

<Tip>
Start with low speed and gradually increase to find your preferred intensity.
</Tip>

<Tip>
Use the bumpers to switch modes by feel—you don't need to look at the screen.
</Tip>

<Tip>
If you accidentally perform a full stop, don't worry—just re-adjust your settings and increase speed to resume.
</Tip>

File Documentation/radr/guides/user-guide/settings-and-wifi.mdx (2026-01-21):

---
title: "Settings and WiFi"
description: "Configure WiFi and access RADR device settings"
sidebarTitle: "Settings & WiFi"
---

This guide covers RADR's settings menu, WiFi configuration, and power management options.

## Accessing Settings

From the main menu, select **Settings** to access the settings menu.

## Settings Menu Options

| Option | Description |
|---|---|
| Go Back | Return to the main menu |
| WiFi Settings | Configure WiFi network connection |
| Update Device | Check for and install firmware updates |
| Restart Device | Reboot the RADR |

### Navigation

- **Right Encoder** — Scroll through options
- **Right Button** — Select the highlighted option
- **Left Button** — Return to main menu

## WiFi Configuration

WiFi connectivity enables over-the-air (OTA) firmware updates for your RADR.

<Info>
WiFi is optional and primarily used for firmware updates. RADR's core functionality (device control) works entirely over Bluetooth.
</Info>

### Setting Up WiFi

<Steps>
<Step title="Open WiFi Settings">
From the settings menu, select **WiFi Settings**.
</Step>

<Step title="Connect to RADR's Access Point">
RADR creates a WiFi access point called **"OSSM Remote Setup"**.

A QR code is displayed on screen for easy connection:

```
WIFI:S:OSSM Remote Setup;T:nopass;;
```

Scan the QR code with your phone, or manually connect to the network:
- **Network Name:** OSSM Remote Setup
- **Password:** None (open network)
</Step>

<Step title="Configure WiFi Credentials">
Once connected to RADR's access point, a configuration portal opens automatically:

1. Select your home WiFi network from the list
2. Enter your WiFi password
3. Save the configuration
</Step>

<Step title="Confirmation">
After successful configuration, you'll see the **"WiFi Connected"** screen:

- **Message:** "Your OSSM Remote is now connected to WiFi."
- RADR is now ready to receive OTA updates
</Step>
</Steps>

### WiFi Configuration Details

| Parameter | Value |
|---|---|
| Access Point Name | OSSM Remote Setup |
| Security | Open (no password) |
| Portal Timeout | 30 seconds |
| Retry Attempts | 5 |

<Warning>
The WiFi setup portal has a 30-second timeout. If the portal times out, restart the WiFi Settings process.
</Warning>

## Update Device

Select **Update Device** to check for and install firmware updates.

<Note>
This feature requires WiFi to be configured. Updates are downloaded and installed over-the-air.
</Note>

## Restart Device

Select **Restart Device** to reboot your RADR. This is useful for:

- Clearing temporary issues
- Applying certain settings changes
- Resetting the Bluetooth state

The device will power off and restart automatically.

## Sleep Mode

From the main menu, select **Sleep** to enter deep sleep mode.

### What Happens in Sleep Mode

1. RADR disconnects any connected devices
2. A shutdown sound plays
3. The display turns off
4. LEDs turn off
5. The device enters ultra-low power mode

### Waking from Sleep

Press any of the three under-screen buttons to wake RADR:

- Left button
- Middle button
- Right button

<Info>
When waking from sleep, RADR performs a full restart and returns to the main menu.
</Info>

### When to Use Sleep Mode

Use sleep mode when:

- You're done using RADR but don't want to fully power off
- You want to conserve battery between sessions
- You want a quick way to pause without disconnecting the power switch

<Tip>
For extended storage, use the physical power switch instead of sleep mode. Sleep mode still consumes minimal power.
</Tip>

## Power Management Summary

| Method | Battery Usage | Wake Method |
|---|---|---|
| Active (connected) | High | N/A |
| Active (idle) | Medium | N/A |
| Sleep Mode | Very Low | Under-screen button |
| Power Switch Off | None | Power switch |

## Troubleshooting

<AccordionGroup>
<Accordion title="WiFi setup portal doesn't appear">
- Ensure you're connected to the "OSSM Remote Setup" network
- Try opening a browser and navigating to 192.168.4.1
- Wait a few seconds after connecting
- Restart WiFi Settings if the portal timed out
</Accordion>

<Accordion title="WiFi doesn't connect to my network">
- Verify your WiFi password is correct
- Ensure your router is within range
- RADR supports 2.4GHz networks only
- Try moving closer to your router
</Accordion>

<Accordion title="Update fails">
- Ensure WiFi is connected and working
- Check that RADR has sufficient battery
- Try the update again
- Contact support if updates consistently fail
</Accordion>

<Accordion title="Device won't wake from sleep">
- Press and hold an under-screen button for 2-3 seconds
- If unresponsive, toggle the power switch off and on
- Ensure RADR has battery charge
</Accordion>
</AccordionGroup>

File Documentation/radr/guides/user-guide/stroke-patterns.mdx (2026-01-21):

---
title: "Stroke Patterns"
description: "Access OSSM stroke patterns through RADR"
sidebarTitle: "Stroke Patterns"
---

RADR provides access to the OSSM's built-in stroke patterns. Patterns are loaded directly from your OSSM when you connect, so the available patterns depend on your OSSM firmware version.

## Accessing Patterns

To access Pattern Mode:

1. Connect to your OSSM
2. From the control screen, press the **right button (Patterns)**
3. Use the **right encoder** to scroll through available patterns
4. Press the **right button** to select a pattern
5. Press the **left button** to cancel without changing

<Info>
Patterns are loaded from your OSSM when you connect. The pattern list may vary depending on your OSSM firmware version.
</Info>

## Controls in Pattern Mode

| Control | Action |
|---|---|
| Right Encoder | Scroll through patterns |
| Left Encoder | Adjust speed (still works) |
| Right Button | Select the highlighted pattern |
| Left Button | Cancel and return to control screen |
| Middle Button | Pause and return to control screen |

<Tip>
The speed control (left encoder) continues to work while in Pattern Mode, allowing you to adjust intensity while browsing patterns.
</Tip>

## Available Patterns

RADR displays all patterns available on your connected OSSM. For detailed information about each pattern—including how the sensation parameter affects behavior—see the OSSM StrokeEngine documentation:

<Card title="OSSM Stroke Patterns" icon="wave-pulse" href="/ossm/Software/motion/stroke-engine/Pattern">
Complete documentation for all OSSM stroke patterns, including Simple Stroke, Teasing or Pounding, Robo Stroke, Half'n'Half, Deeper, Stop'n'Go, Insist, and more.
</Card>

## Tips

<Tip>
Patterns work in combination with your speed setting. A pattern at 20% speed feels very different from the same pattern at 80% speed. Experiment with different combinations.
</Tip>

<Tip>
Start with **Simple Stroke** to get comfortable with the controls, then experiment with other patterns.
</Tip>

<Tip>
New patterns may be added through OSSM firmware updates. Check for firmware updates to access the latest pattern libraries.
</Tip>

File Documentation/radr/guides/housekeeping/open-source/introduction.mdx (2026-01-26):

---
title: "What Open Source Means"
description: "Learn about RADR's open source licensing under CERN OHL-S v2, and what this means for contributors."
---

## Open Source Hardware

RADR is genuinely open source hardware. The project is licensed under the **CERN Open Hardware Licence Version 2 - Strongly Reciprocal (CERN-OHL-S v2)**, the same license used by the [OSSM](/ossm/guides/housekeeping/open-source/introduction).

<Info>
The strongly reciprocal nature of CERN-OHL-S v2 ensures that derivative works remain open source, protecting the community's collective efforts.
</Info>

## What This Means for You

When you contribute to the RADR GitHub repository, your contributions fall under the same CERN-OHL-S v2 license. You can find the complete license text in the [licence documentation](/radr/guides/housekeeping/open-source/licence).

### You Can

- **Use** RADR designs and software freely
- **Study** how RADR works and learn from its design
- **Modify** the hardware and software to suit your needs
- **Share** your modified versions with others
- **Build and sell** RADR units (with attribution and source sharing)

### You Must

- **Share alike** — If you distribute modifications, they must be under the same license
- **Provide source** — Make your modified designs available when distributing products
- **Retain notices** — Keep copyright and license notices in place

## Source Files

All RADR source files are available on GitHub:

<CardGroup cols={2}>
<Card title="Hardware Files" icon="microchip" href="https://github.com/researchanddesire/radr-wireless-remote/tree/main/Hardware">
PCB designs, schematics, and 3D print files.
</Card>

<Card title="Firmware Source" icon="code" href="https://github.com/researchanddesire/radr-wireless-remote/tree/main/Software">
Complete ESP32 firmware source code.
</Card>
</CardGroup>

### Hardware

- **PCB Design Files** — Altium Designer project files for the main board
- **Schematics** — Full circuit schematics in PDF and native formats
- **Bill of Materials** — Complete parts list with manufacturer part numbers
- **3D Print Files** — STEP and STL files for the enclosure

### Software

- **Firmware** — ESP32-S3 firmware written in C++ using PlatformIO
- **Libraries** — Custom libraries for display, Bluetooth, and device control
- **Device Registry** — JSON configuration for supported Buttplug.io devices

## Community Contributions

Open source means contributions can come from anyone, anywhere. Before using or contributing to RADR:

- Review the [safety guidelines](/ossm/guides/housekeeping/safety) thoroughly
- Understand your personal risks and boundaries
- Familiarize yourself with the contribution process

<DiscordInvite community="kinky-makers" />

## Why Open Source?

We believe in:

1. **Transparency** — You can verify exactly what your device does
2. **Repairability** — Full documentation means you can fix and maintain your device
3. **Customization** — Modify the design to suit your specific needs
4. **Community** — Build on the work of others and contribute back
5. **Longevity** — Open designs outlive any single company

## Related Projects

RADR is part of the Research And Desire ecosystem, alongside other open source projects:

- [OSSM (Open Source Sex Machine)](/ossm/guides/getting-started/introduction)
- [Lockbox](/lkbx/quick-start)
- [Deepthroat Trainer](/dtt/quick-start)

All share the same commitment to open source hardware and community-driven development.

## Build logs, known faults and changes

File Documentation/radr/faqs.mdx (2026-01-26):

---
title: "Frequently Asked Questions"
description: "Common questions and answers about the RADR wireless remote"
---

Find answers to common questions about setting up, using, and troubleshooting your RADR wireless remote.

## Controls & Buttons

<AccordionGroup>
<Accordion title="One bumper button feels different or has no tactile feedback">
Each bumper button on the RADR has two microswitches wired in parallel for redundancy. If one bumper feels different from the other or has reduced/no tactile feedback, this could be caused by:

- **Assembly alignment** — Print inconsistencies or alignment during assembly can cause one microswitch to activate differently
- **Screw tension** — A slightly over-torqued screw can affect the bumper's tactile feel

**To troubleshoot:**

1. Locate the single screw on the rear of the remote, directly behind the affected bumper
2. Try loosening the screw slightly (quarter turn)
3. Test the bumper feel again

If both bumpers still function (the button registers on screen) but one has reduced tactile feedback, the remote is working as designed—some variation is normal.

<Warning>
If the button has absolutely no tactile feedback or doesn't register presses at all, the microswitch may be defective. Contact support for a replacement.
</Warning>

<Card title="Contact Support" icon="headset" href="mailto:support@researchanddesire.com">
Get help from our support team.
</Card>
</Accordion>

<Accordion title="What do the bumper buttons do?">
The left and right bumper buttons on the top edge of the RADR switch between control modes when connected to an OSSM:

| Button | Function |
|---|---|
| Left Bumper (`<<`) | Switch to previous mode |
| Right Bumper (`>>`) | Switch to next mode |

The modes cycle through: **Depth → Sensation → Stroke → Depth**

<Card title="OSSM Controls Guide" icon="sliders" href="/radr/guides/user-guide/ossm-controls">
Learn more about controlling your OSSM with RADR.
</Card>
</Accordion>
</AccordionGroup>

## Connectivity

<AccordionGroup>
<Accordion title="How do I connect RADR to my OSSM?">
To connect your RADR to an OSSM:

1. Power on both devices
2. On RADR, select **Device Search** from the main menu
3. Wait for the scan to complete (about 5 seconds)
4. Select your OSSM from the device list
5. Wait for the connection confirmation sound

<Card title="Quick Start Guide" icon="rocket" href="/radr/guides/getting-started/quick-start">
Step-by-step instructions for getting started.
</Card>
</Accordion>

<Accordion title="Why won't RADR find my OSSM?">
If RADR can't find your OSSM during scanning:

1. **Check distance** — Move RADR closer to your OSSM (within 10 meters)
2. **Power cycle both devices** — Turn both off, wait 10 seconds, then power on
3. **Check OSSM firmware** — Ensure your OSSM is running compatible firmware
4. **Disable other Bluetooth connections** — Disconnect other devices that may be connected to your OSSM

<Card title="Device Support" icon="list-check" href="/radr/guides/reference/device-support">
See which devices are compatible with RADR.
</Card>
</Accordion>

<Accordion title="Is RADR compatible with older OSSM board versions?">
Yes, RADR is compatible with all OSSM PCB versions (v2.1, v2.3, and newer). The board version doesn't affect RADR compatibility—only the firmware version matters.

**To use RADR with your OSSM:**

1. Update your OSSM firmware to version 2.0.0 or later using the [Web Flasher](/ossm/guides/getting-started/web-flasher)
2. Power on both devices
3. RADR will automatically detect and connect to your OSSM

<Note>
The main differences between board versions relate to motor compatibility (v2.3 includes a capacitor for Gold Motor support) rather than RADR functionality. All board versions support RADR once the firmware is updated.
</Note>

<Card title="Flash your OSSM" icon="microchip" href="/ossm/guides/getting-started/web-flasher">
Update your OSSM firmware for RADR compatibility.
</Card>
</Accordion>
</AccordionGroup>

## Battery & Charging

<AccordionGroup>
<Accordion title="My RADR makes a rattling sound when shaken">
A slight rattling sound when shaking the device is normal. This is caused by the internal battery pressing against a small piece of foam inside the enclosure.

The rattling does not affect functionality — nothing is broken.

If the sound bothers you, you can open the back panel and add a slightly thicker piece of foam to dampen the rattling.
</Accordion>

<Accordion title="How long does the battery last?">
RADR typically provides 4+ hours of active use on a full charge. Battery life varies based on screen brightness, vibration feedback usage, and connection activity.

<Card title="Battery & Power" icon="battery-full" href="/radr/Hardware/specifications/battery-and-power">
Technical details about battery monitoring and charging.
</Card>
</Accordion>

<Accordion title="How do I charge RADR?">
Connect a USB-C cable to the port on the top edge of RADR. The device can be used while charging.
</Accordion>
</AccordionGroup>

## Support

<Accordion title="Who should I contact for RADR support?">
For technical support or questions about your RADR, contact our support team:

- **Email:** [support@researchanddesire.com](mailto:support@researchanddesire.com)

<DiscordInvite community="rad" />
</Accordion>

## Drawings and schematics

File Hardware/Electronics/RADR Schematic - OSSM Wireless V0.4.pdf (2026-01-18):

# Big Brain ESP32

## ESP32-S3-WROOM-1-N16R8

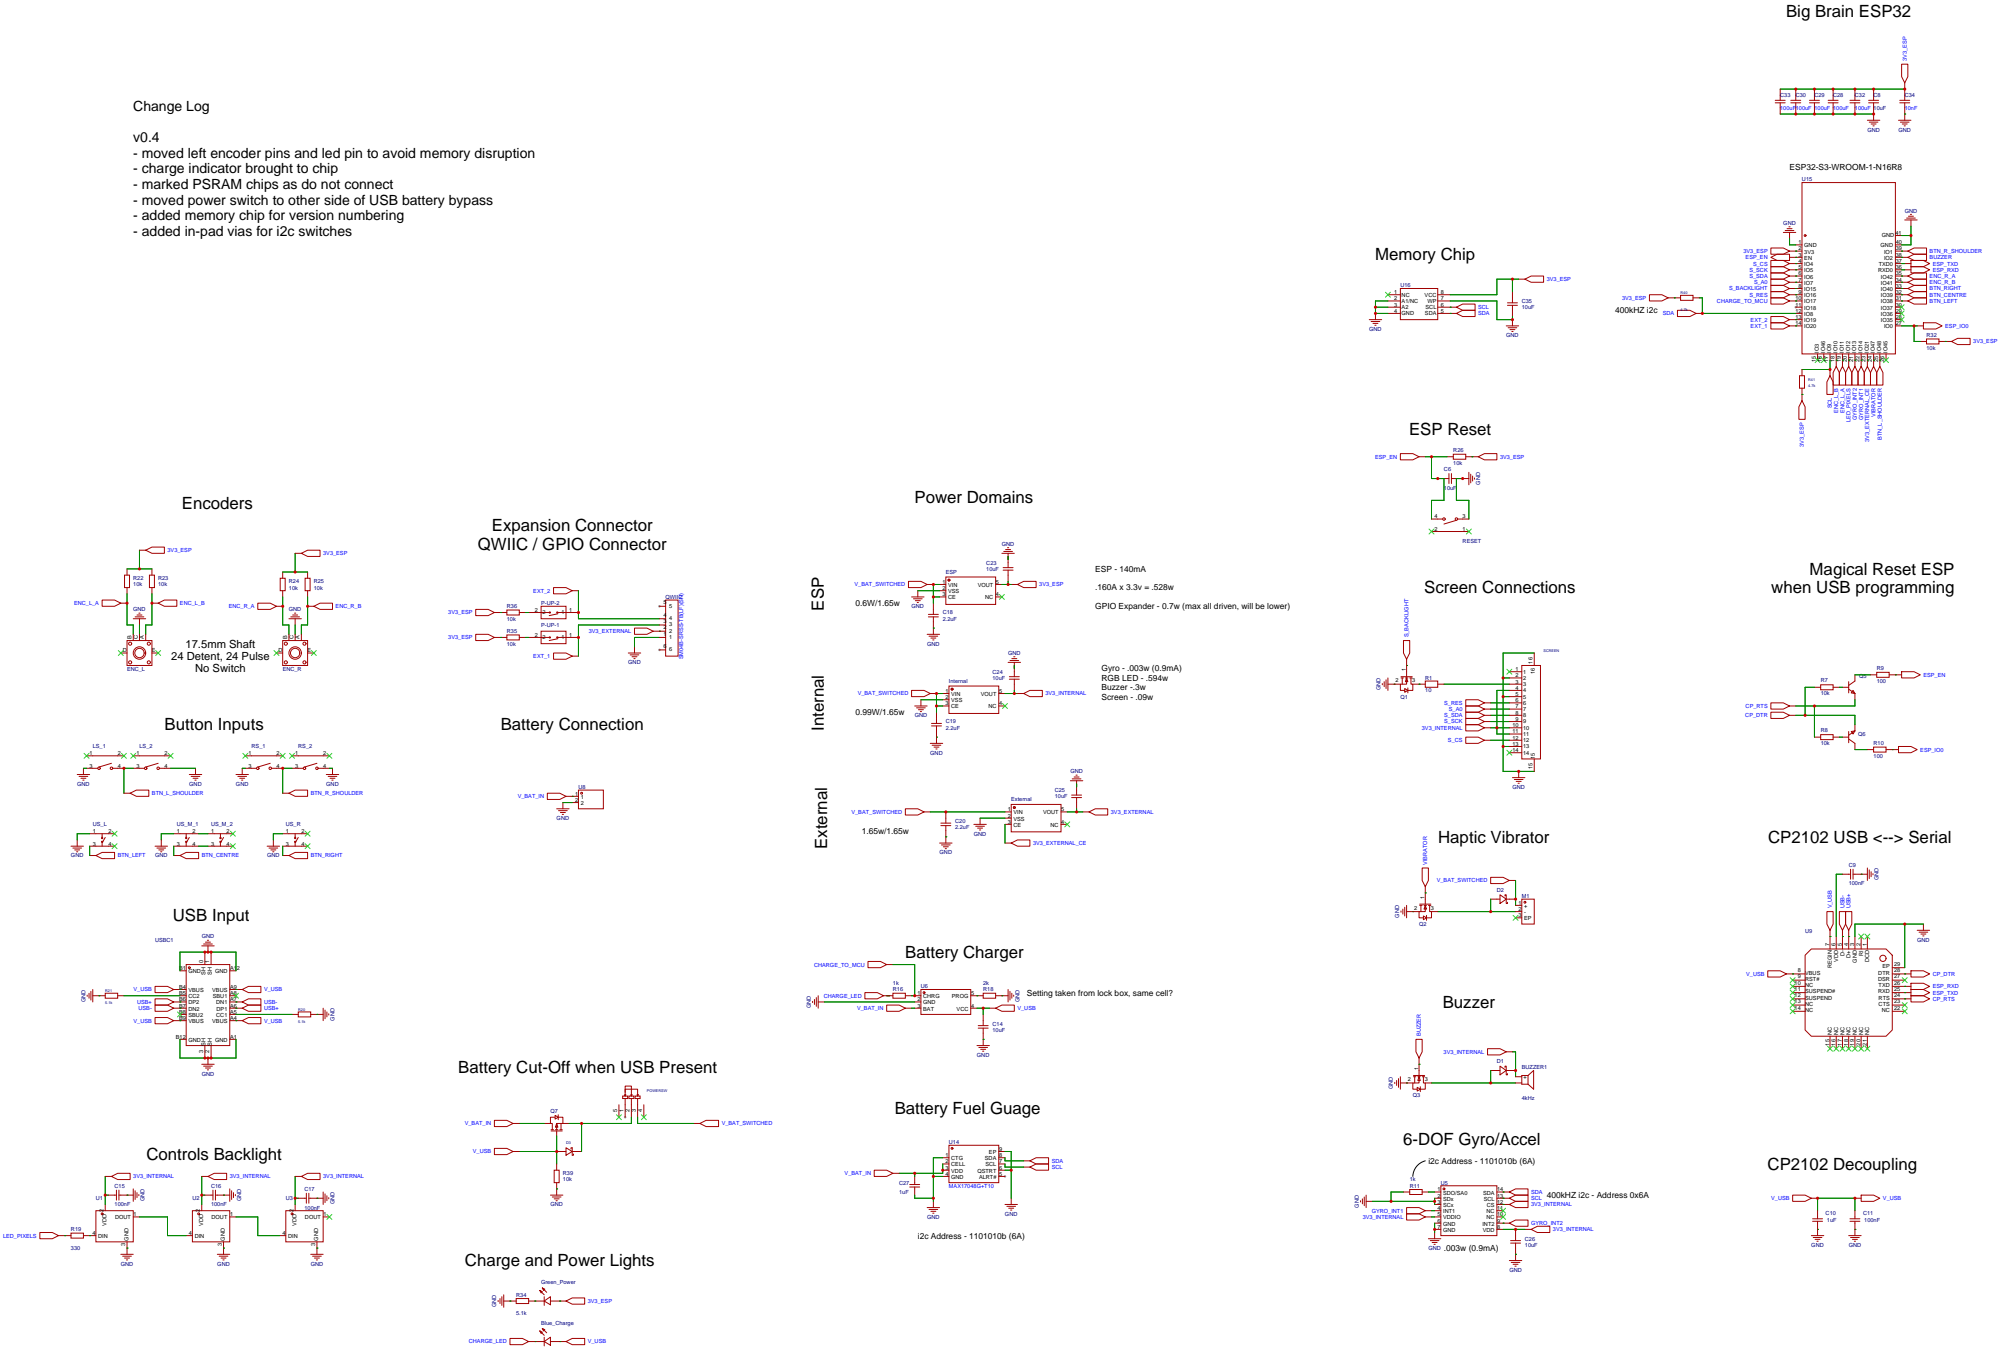
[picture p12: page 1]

Change Log
- moved left encoder pins and led pin to avoid memory disruption
- charge indicator brought to chip
- marked PSRAM chips as do not connect
- moved power switch to other side of USB battery bypass
- added memory chip for version numbering
- added in-pad vias for i2c switches

V_BAT_SWITCHED
GPIO Expander - 0.7w (max all driven, will be lower) 0.6W/1.65w

Setting taken from lock box, same cell?

Battery Cut-Off when USB Present

Charge and Power Lights

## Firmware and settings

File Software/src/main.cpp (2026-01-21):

#include <Arduino.h>

#include <OneButton.h>
#include <freertos/FreeRTOS.h>
#include <freertos/task.h>

#include "components/AnimatedIcons.h"
#include "constants.h"
#include "esp_log.h"
#include "pins.h"
#include "services/battery.h"
#include "services/buzzer.h"
#include "services/coms.h"
#include "services/display.h"
#include "services/encoder.h"
#include "services/imu.h"
#include "services/leds.h"
#include "services/lastInteraction.h"
#include "services/memory.h"
#include "services/vibrator.h"
#include "services/wm.h"
#include "state/remote.h"

// Function declaration for resetting middle button counter
extern void resetMiddleButtonCounter();

OneButton leftShoulderBtn;
OneButton rightShoulderBtn;
OneButton underLeftBtn;
OneButton underCenterBtn;
OneButton underRightBtn;

// Global variables for middle button press tracking
static int middleButtonPressCount = 0;

// Function to reset middle button counter (can be called from device)
void resetMiddleButtonCounter() { middleButtonPressCount = 0; }

void setup() {
    Serial.begin(115200);

    // Version 1.x of the PCB Boards cannot use PSRAM
    if (psramInit()) {
        ESP_LOGI(TAG, "PSRAM initialized");
    } else {
        ESP_LOGI(TAG, "PSRAM initialization failed");
    }

    ESP_LOGD(TAG, "PSRAM found: %d", psramFound());

    // init buttons
    leftShoulderBtn = OneButton(pins::BTN_L_SHOULDER, true, true);
    leftShoulderBtn.attachClick(
        []() { setNotIdle("left_shoulder_btn"); stateMachine->process_event(left_shoulder_pressed()); });
    rightShoulderBtn = OneButton(pins::BTN_R_SHOULDER, true, true);
    rightShoulderBtn.attachClick(
        []() { setNotIdle("right_shoulder_btn"); stateMachine->process_event(right_shoulder_pressed()); });
    underLeftBtn = OneButton(pins::BTN_UNDER_L, true, true);
    underLeftBtn.attachClick(
        []() { setNotIdle("under_left_btn"); stateMachine->process_event(left_button_pressed()); });
    underCenterBtn = OneButton(pins::BTN_UNDER_C, true, true);
    underCenterBtn.attachClick([]() {
        setNotIdle("under_center_btn");
        middleButtonPressCount++;
        if (middleButtonPressCount == 1) {
            // First press action
            stateMachine->process_event(middle_button_pressed());
        } else if (middleButtonPressCount >= 2) {
            // Second press action
            resetMiddleButtonCounter();
            stateMachine->process_event(middle_button_second_press());
        }
    });
    underRightBtn = OneButton(pins::BTN_UNDER_R, true, true);
    underRightBtn.attachClick(
        []() { setNotIdle("under_right_btn"); stateMachine->process_event(right_button_pressed()); });

    initMemoryService();
    initEncoderService();
    initFastLEDs();
    initWM();
    initDisplay();
    initBuzzer();
    initVibrator();
    initBLE();
    initStateMachine();
    initBattery();

    // initIMUService();
    // updateIMUReadings();

    setupAnimatedIcons();
    setupIdleMonitor();

    xTaskCreatePinnedToCore(
        [](void *pvParameters) {
            while (true) {
                vTaskDelay(10);
                leftShoulderBtn.tick();
                rightShoulderBtn.tick();
                underLeftBtn.tick();
                underCenterBtn.tick();
                underRightBtn.tick();
                wm.process();
            }
        },
        "buttonTask", 6 * configMINIMAL_STACK_SIZE, NULL,
        configMAX_PRIORITIES - 1, NULL, 0);
}

void loop() {
    // delete the loop task. Everything is managed by the state machine now.
    vTaskDelete(NULL);
}

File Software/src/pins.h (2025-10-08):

#ifndef PINS_H
#define PINS_H
#pragma once

namespace pins {
    // Screen pins (from Board Config.md)
    constexpr uint8_t TFT_CS = 4;    // Screen Cable Select
    constexpr uint8_t TFT_DC = 7;    // Screen A0
    constexpr uint8_t TFT_RST = 16;  // Screen Reset
    constexpr uint8_t TFT_SCLK = 5;  // Screen Clock
    constexpr uint8_t TFT_MOSI = 6;  // Screen Data
    constexpr uint8_t TFT_BL = 15;   // Screen Backlight

// LED strip
#ifdef BOARD_HAS_PSRAM
    constexpr uint8_t LEFT_ENCODER_B = 11;
    constexpr uint8_t LEFT_ENCODER_A = 10;
    constexpr uint8_t LED_PIN = 12;  // WS2812B LED pin
#else
    constexpr uint8_t LEFT_ENCODER_B = 35;
    constexpr uint8_t LED_PIN = 37;  // WS2812B LED pin
    constexpr uint8_t LEFT_ENCODER_A = 36;
#endif
    constexpr uint8_t NUM_LEDS = 3;       // Number of LEDs
    constexpr uint8_t BUZZER_PIN = 2;     // Buzzer
    constexpr uint8_t VIBRATOR_PIN = 47;  // Vibrator

    // I2C pins for battery fuel gauge
    constexpr uint8_t I2C_SDA = 8;  // I2C SDA
    constexpr uint8_t I2C_SCL = 9;  // I2C SCL

    // Button pins (from Board Config.md)
    constexpr uint8_t BTN_R_SHOULDER = 1;   // Right Shoulder Button
    constexpr uint8_t BTN_L_SHOULDER = 48;  // Left Shoulder Button
    constexpr uint8_t BTN_UNDER_L = 38;     // Under Screen Left Button
    constexpr uint8_t BTN_UNDER_C = 39;     // Under Screen Centre Button
    constexpr uint8_t BTN_UNDER_R = 40;     // Under Screen Right Button

    // Legacy aliases for compatibility

    constexpr uint8_t RIGHT_ENCODER_A = 42;
    constexpr uint8_t RIGHT_ENCODER_B = 41;

    // MCP23017 pin definitions (if still used)
    constexpr uint8_t BUZZER = 1;
    constexpr uint8_t GYRO_INT1 = 3;
    constexpr uint8_t GYRO_INT2 = 4;
    constexpr uint8_t VIBRATOR = 6;
    constexpr uint8_t REGULATOR_EN = 7;
    constexpr uint8_t FUEL_GAUGE = 8;
    constexpr uint8_t EXT_IO3 = 9;
    constexpr uint8_t EXT_IO4 = 10;

    // MCP23017 interrupt pin
    constexpr uint8_t MCP_INT_PIN = 16;

    // BQ27220 I2C address
    constexpr uint8_t BQ27220_ADDR = 0x55;

}

#endif

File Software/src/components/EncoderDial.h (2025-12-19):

#ifndef ENCODERDIAL_H
#define ENCODERDIAL_H

#include <Arduino.h>

#include <Adafruit_MCP23X17.h>
#include <Adafruit_ST77xx.h>
#include <map>

#include "DisplayObject.h"
#include "esp_log.h"
#include "pins.h"
#include "services/buzzer.h"
#include "services/display.h"
#include "services/leds.h"
#include "services/vibrator.h"
// Adafruit GFX fonts
#include <AiEsp32RotaryEncoder.h>
#include <Fonts/FreeSansBold9pt7b.h>  // Reduced from 12pt to 9pt for better fit
#include <vector>

class EncoderDial : public DisplayObject {
  private:
    bool lastButtonState = false;
    std::map<String, float *> parameters;
    const uint16_t color;
    std::vector<uint16_t> colors;  // Optional per-parameter colors
    int minValue = 0;
    int maxValue = 100;
    int *focusedIndex = nullptr;
    std::map<String, int> lastParameterValues;
    int lastFocusedIndex = -1;
    bool isFirstDraw =
        true;  // Track if this is the first draw to avoid unnecessary clearing

    // LED mapping settings
    bool mapToLeftLed = false;
    bool mapToRightLed = false;

    void drawArcDirect(int arcRadius, int centerX, int centerY, int fillSteps,
                       int steps, int circleRadius, bool isFocused,
                       uint16_t activeColor) {
        int startAngle = 0;
        int endAngle = 270;

        for (int i = steps - 1; i >= 0; i--) {
            float angle = (startAngle + (i * (endAngle - startAngle) / steps)) *
                          PI / 180.0;
            int x = centerX + arcRadius * cos(angle + 3 * PI / 4);
            int y = centerY + arcRadius * sin(angle + 3 * PI / 4);
            if (i < fillSteps || i == 0) {
                tft.fillCircle(x, y, circleRadius,
                               isFocused ? activeColor : ST77XX_WHITE);
            } else {
                tft.fillCircle(x, y, circleRadius, 0x7BEF);  // Dark gray color
            }
        }
    }

    AiEsp32RotaryEncoder &encoder;

  public:
    struct Props {
        AiEsp32RotaryEncoder *encoder = nullptr;
        std::map<String, float *> parameters;
        int *focusedIndex = nullptr;
        int16_t x = -1;
        int16_t y = -1;
        int16_t width = 90;
        int16_t height = 90;
        int minValue = 0;
        int maxValue = 100;
        bool mapToLeftLed = false;   // Map active color to left LED (LED 0)
        bool mapToRightLed = false;  // Map active color to right LED (LED 2)
    };

    explicit EncoderDial(const Props &props)
        : DisplayObject(props.x, props.y, props.width, props.height),
          parameters(props.parameters),
          color(ST77XX_WHITE),
          encoder(*props.encoder),
          mapToLeftLed(props.mapToLeftLed),
          mapToRightLed(props.mapToRightLed) {
        focusedIndex = props.focusedIndex;

        minValue = props.minValue;
        maxValue = props.maxValue;

        if (x == -1) {
            x = Display::WIDTH / 2 - width / 2;
        }

        if (y == -1) {
            y = Display::PageY + Display::PageHeight / 2 - height / 2;
        }
    }

    void setParameters(const std::map<String, float *> &newParams) {
        if (newParams != parameters) {
            parameters = newParams;
            isDirty = true;
        }
    }

    void setParameterColors(const std::vector<uint16_t> &paramColors) {
        colors = paramColors;
        isDirty = true;
    }

    void setActiveParameterColor(int paramIndex, uint16_t activeColor) {
        // Resize colors vector if needed
        if (colors.size() <= paramIndex) {
            colors.resize(paramIndex + 1, ST77XX_WHITE);
        }
        colors[paramIndex] = activeColor;
        isDirty = true;
    }

    bool shouldDraw() override {
        // use focused index to get the parameter value
        int currentValue = encoder.readEncoder();
        if (parameters.size() > 0) {
            auto it = parameters.begin();
            std::advance(it, *focusedIndex);
            if (it != parameters.end() && it->second != nullptr) {
                *(it->second) = constrain(currentValue, minValue, maxValue);
            }
        }

        if (lastFocusedIndex != *focusedIndex) {
            return true;
        }

        if (lastParameterValues.size() != parameters.size()) {
            return true;
        }

        for (const auto &param : parameters) {
            auto currentValue = 0;
            if (param.second != nullptr) {
                currentValue = *(param.second);
            }
            auto it = lastParameterValues.find(param.first);
            if (it == lastParameterValues.end() || it->second != currentValue) {
                return true;
            }
        }

        return false;
    }

    void draw() override {
        if (xSemaphoreTake(displayMutex, pdMS_TO_TICKS(50)) == pdTRUE) {
            // Only clear entire area on first draw or focus change
            if (isFirstDraw || lastFocusedIndex != *focusedIndex) {
                tft.fillRect(x, y, width, height, ST77XX_BLACK);
                isFirstDraw = false;
            } else {
                // For parameter value updates, we'll redraw over existing arcs
                // This reduces flicker significantly
            }

            int steps = 100;
            int circleRadius = 2;
            int maxArcRadius = width / 2 - circleRadius;
            int arcSpacing =
                maxArcRadius / (parameters.size() + 1);  // Space between arcs

            int centerX = x + width / 2;
            int centerY = y + height / 2;

            // Draw arcs for each parameter
            int arcIndex = 0;
            for (const auto &param : parameters) {
                int currentRadius = maxArcRadius - (arcIndex * arcSpacing);
                int paramValue = 0;
                if (param.second != nullptr) {
                    paramValue = constrain((int)roundf(*(param.second)),
                                           minValue, maxValue);
                }
                int range = maxValue - minValue;
                int fillSteps =
                    range > 0 ? (int)lround(
                                    ((double)(paramValue - minValue) * steps) /
                                    (double)range)
                              : steps;
                uint16_t arcColor =
                    (arcIndex < (int)colors.size()) ? colors[arcIndex] : color;

                // Only redraw arc if value changed or if it's focused parameter
                // or first draw
                auto lastValueIt = lastParameterValues.find(param.first);
                bool valueChanged = (lastValueIt == lastParameterValues.end() ||
                                     lastValueIt->second != paramValue);
                bool isFocused = (arcIndex == *focusedIndex);

                // For single parameter encoders, always consider the parameter
                // as focused
                if (parameters.size() == 1) {
                    isFocused = true;
                }
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

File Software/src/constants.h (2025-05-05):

#pragma once

// Display dimensions
#define DISPLAY_WIDTH 320
#define DISPLAY_HEIGHT 240

// Display colors (using ST77XX color definitions)
#define COLOR_BLACK 0x0000
#define COLOR_WHITE 0xFFFF
#define COLOR_RED 0xF800
#define COLOR_GREEN 0x07E0
#define COLOR_BLUE 0x001F
#define COLOR_YELLOW 0xFFE0
#define COLOR_MAGENTA 0xF81F
#define COLOR_CYAN 0x07FF
#define COLOR_DARK_GREY 0x7BEF

// Display text sizes
#define TEXT_SIZE_SMALL 1
#define TEXT_SIZE_MEDIUM 2
#define TEXT_SIZE_LARGE 3

// Display margins and spacing
#define MARGIN_SMALL 10
#define MARGIN_MEDIUM 20
#define MARGIN_LARGE 40

// Progress bar dimensions
#define PROGRESS_BAR_WIDTH 20
#define PROGRESS_BAR_HEIGHT 180

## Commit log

2025-04-22 tests basic IO and vibrator
    [main.cpp]
2025-04-25 fuel gauge reading
    Fuel gauge now reading, accelerometer is connecting but can't read from it.
2025-04-25 encoders were missing
2025-05-05 move leds to service
2025-05-05 battery service
2025-05-07 Pattern system for motor
2025-05-25 Refactor MCP button handling with debounce logic and remove interrupt-based approach for button state management
2025-05-26 Refactor main application logic by removing unused control variables, optimizing I2C device scanning, and enhancing ESP-NOW initialization. Adjust button handling and logging verbosity in various com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
2025-05-26 Add emergency stop functionality with visual feedback and update encoder handling in controller task
2025-05-26 Add charging status check and update battery logging; refactor icon positioning calculation
2025-09-16 fix encoders
2025-09-19 Move device instance
2025-09-20 Encoder acceleration setting that feels good on 12 step encoders
2025-09-24 Update "STOP" button to behave as "PAUSE" button.
2025-09-24 Major UX refactor to reduce memory consumption, increase FPS, improve communication to user when finding devices, and improve LinearRailGraph calculations for display.
2025-09-25 vibrator buzzer and leds
    [EncoderDial.h, LinearRailGraph.h]
2025-09-26 Pull device pattern descriptions
2025-09-26 Fix dynamic text rendering and add documentation
    [DynamicText.h, Sizes.h]
2025-09-27 Prevent skipped encoder send - Frequent edge case
    [encoder.cpp]
2025-09-27 Relocated menu setEncoderValue inside isInCorrectState, resolves RAD-629
    [menus.cpp]
2025-09-27 Optimization for initializing encoder for menus. Resolves RAD-629
    [menus.cpp]
2025-09-27 Improve battery isCharging logic, but also bypass isCharging for icon update completely.
2025-09-27 Add leftEncoderMonitor, to allow (optionally) for device leftEncoderInput to be used in nested menus with status bar display of value. Misc UI improvements.
2025-09-28 Update pause state, using new double button action for 'space bar'. Allow on-the-fly dynamic colors for DynamicText and TextButton. Misc UX tweaks for better experience when in housing.
2025-09-28 Simulated Tabbed UX support and implementation for OSSM Device. Encoder LED maps to Encoder Active Color with gamma correction for color map.
    [EncoderDial.h, TextButton.h, leds.cpp]
2025-09-28 Change OSSM Home button to a "Menu" button, put it in a disabled state.
2025-09-28 restoring pin listener for Menu Button, setting NO_PIN is overridden elsewhere for hardware buttons, so this did nothing. Disabled button functionality needs enforcement!
2025-09-29 Initialize monitored leftEncoder Value to zero before first read. Resolves RAD-633
    [leftEncoderMonitor.cpp]
2025-09-29 Raise encoder arcs 5px to make room for full width pattern text
2025-09-29 Set up for Device Settings Menu, which disables OSSM Menu button. Better Paused red LED clearning behavior
2025-09-29 device_menu changed to issue soft pause and return to device_draw_control on any middle button state click
2025-10-06 Restore onLeftEncoderChange action for default style devices (non-persistent-monitoring)
2025-10-14 feat working on buttplug io support for N toys
    [cupido.yml, motorbunny.yml]
2025-10-14 working on buttplug io
    [motorbunny.json]
2025-10-17 Misc LED task cleanup. Improve main_menu UX LED glow transition from device_control LEDs
2025-10-17 Fix menu wrap encoder behavior (seemingly caused by variable collision)
    [menus.cpp]
2025-11-13 fix: pin espressif32 version
2025-12-18 Fixed all the memory related bugs
    [main.cpp]
2026-01-18 Reformatted file structure
    Make Hardware and Software folders to more easily navigate.
    [Buttons.step, OSSM Remote Clip - Extrusion Bottom Release (M6x12).step, Power Switch.step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]
2026-01-19 fixed excel bom
    [Wireless Remote BoM (RADR).xlsx]
2026-01-19 Create README.md with print guidance
    Added print guidance and settings for hardware parts.
2026-01-19 PCB files updated
    [1_Schematic - OSSM Wireless V0.4.schdoc, PCB - OSSM Wireless v0.4.pcbdoc]
2026-01-21 Switched from digital write on/off to pwm to control the screen brightness more granularly
2026-01-21 Now any button press or encoder change will set the device state to Notidle
2026-01-21 Fixed an issue where the shared pwm channel caused the screen to turn off
    [display.cpp]
2026-01-21 Add power saving docs to correct location, remove misplaced file
